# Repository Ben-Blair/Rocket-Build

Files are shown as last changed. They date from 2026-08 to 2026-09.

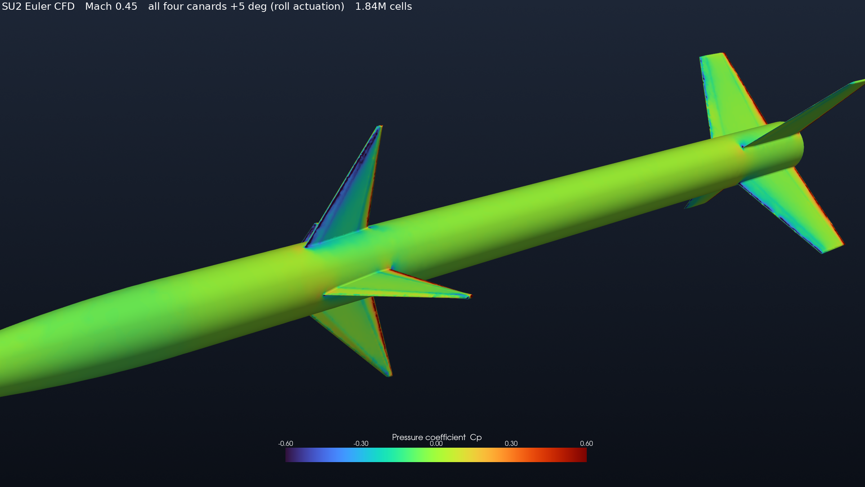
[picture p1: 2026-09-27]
out/cfd/renders/07_roll5_hero.png

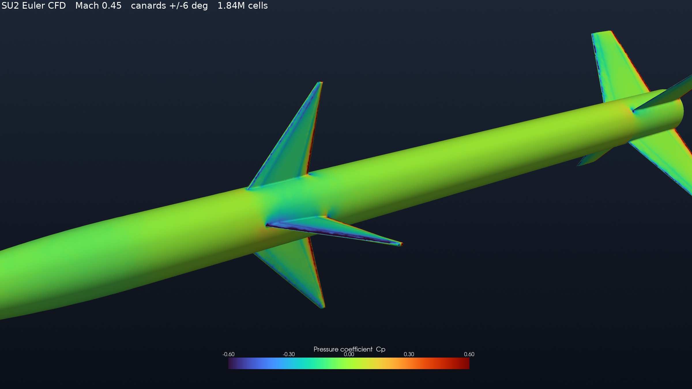
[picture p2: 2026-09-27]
out/cfd/renders/01_vehicle_cp.png

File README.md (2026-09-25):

# RocketSenior — canard-guided high power rocket

Senior capstone project: demonstrate closed-loop lateral guidance of a high power rocket
using forward canards, and handle the canard-wake-on-aft-fin interference problem
correctly.

This repository currently holds the **preliminary sizing tool**. It exists to answer the
questions you have to answer *before* you can draw anything in OpenRocket: how big is the
tube, how big are the fins, which motor, and can the canards actually do anything.

## Why a sizing tool instead of just using OpenRocket

OpenRocket is a verification tool. It answers "is *this specific* rocket stable, and how
high does it go." It cannot answer "what should my rocket be," because that depends on
constraints it knows nothing about:

- the internal diameter needed to house four canard servos (this sets your airframe size),
- the lateral acceleration you need for a visible manoeuvre,
- the static margin you are willing to trade away to get control authority,
- whether the canard wake reverses the sign of your roll moment.

This tool computes those, converges on a baseline, and then prints the numbers to type
into OpenRocket for an independent cross-check. Use both. Disagreement between them is
information.

## Quick start

```bash
pip install -r requirements.txt

python scripts/packaging_report.py   # what diameter do the actuators force on you?
python scripts/fetch_motors.py --diameter 54 --classes J K   # real thrust curves
python scripts/motor_trade.py        # rank every real L2 motor against the airframe
python scripts/sweep.py              # which (tube, motor, fin) combos meet requirements?
python scripts/baseline.py --plot    # full analysis + OpenRocket entry values
```

## Layout

```
out/
  RocketSenior.ork   GENERATED by scripts/make_ork.py -- do not hand-edit, see below
```

### The .ork is a build artifact, not the design

`out/RocketSenior.ork` is written from the same `DesignParams` the Python tool uses, and
`scripts/openrocket_check.py` regenerates it on every run. That is the point: the two
models cannot drift apart.

It also means **anything you change in the OpenRocket GUI and save back to that path is
destroyed the next time you run the check.** Open it to look, simulate, and cross-check
freely. If you want to tinker, `Save As` somewhere outside `out/` first. If a change is
worth keeping, it belongs in `design/configure.py` or `scripts/make_ork.py`, so that the
next regeneration carries it forward.

```
design/
  atmosphere.py   US Standard Atmosphere 1976, troposphere
  aero.py         Barrowman CNa & CP buildup, component drag buildup
  avionics.py     nav bay / nose packing, and the D7 flight computer trade
  bay.py          the printed canard bay: servo pockets, bearing seats, retainers
  configure.py    parameter set -> full vehicle -> requirement scoring, and the
                  frozen baseline airframe every script imports
  control.py      canard pitch authority, roll authority, wake interference, crossrange
  estimation.py   D8: observability per flight phase, attitude error budget, sensor specs
  flight_computer.py  the Stage 2 board: BOM, power budget, log budget, board envelope
  flutter.py      fin flutter margin
  geometry.py     nose / tube / fin set definitions, Barrowman CP geometry
  hinge.py        the hinge as a load path: shaft, bearing, coupling, root joint
  joints.py       all four tube joints -- a coupler costs bore, not length
  mass.py         geometric structural mass + editable subsystem budget, CG
  materials.py    material allowables, in one place
  motors.py       RASP .eng thrust curve parser + placeholder generic motors
  onshape.py      minimal Onshape REST API client
  onshape_build.py  emits Onshape Part Studio feature JSON
  packaging.py    actuator bay packaging + hinge moment + servo torque margin
  recovery.py     dual-deploy sizing, descent time, wind drift, soft-goods packing
  seal.py         the aft gas seal and the internal bulkhead, sized as pistons
  horizontal.py   horizontal-launch 3-DOF: fly the manoeuvre, then score the turn
  trajectory.py   3-DOF RK4 ascent to apogee
  tube_section.py airframe survival where holes are cut through it
  venting.py      static ports and bay vents: which volumes the altimeter may sense
scripts/
  agility_sweep.py      how agile can this airframe legally be, and what stops it
  avionics_report.py    nav bay + nose packing report and verdict
  avionics_trade.py     D7: the three flight computer architectures
  baseline.py           detailed baseline report + OpenRocket values
  bay_report.py         printed canard bay geometry and margins
  burn_time_study.py    why burn time is not a control-time knob
  canard_sweep.py       drives the CAD canards through +/-8 deg, checks clearances
  estimation_trade.py   D8: the four sensor sets, and what the estimate can know
  fetch_motors.py       download real .eng thrust curves from ThrustCurve.org
  hinge_report.py       hinge stack loads, fits and buildability
  horizontal_agility_sweep.py  the same search flown FLAT, where the answer changes
  make_*.py             build geometry in Onshape from the design modules
  motor_trade.py        rank every available L2 motor against the baseline airframe
  openrocket_check.py   automated cross-check against OpenRocket's engine
  packaging_report.py   diameter vs servo class table
  place_*.py            place built parts into Onshape Assembly 1
  recovery_study.py     descent, drift and the recovery footprint constraint
  robustness.py         Monte Carlo on static margin; sets the aft fin size
  flight_computer_report.py  the Stage 2 board's BOM, power, logging and envelope
  seal_report.py        the aft gas seal argument and check
  sil_demo.py           software-in-the-loop: closed-loop roll hold, bank-to-turn,
                        R12 failsafe -- synthetic sensors, no hardware
  sweep.py              design space sweep against requirements
  verify_cad.py         cross-check the design numbers against the Onshape model
  virtual_flight.py     3-D virtual flight: ballistic, skid-to-turn, bank-to-turn
docs/
  00-requirements.md    requirements, constraints, scoping, regulatory actions
  01-next-steps.md      ordered plan, the state of play, and 36 corrections
  02-motor-selection.md L2 motor trade study and decision
  03-openrocket-correlation.md  automated cross-check against OpenRocket's engine
  04-bill-of-materials.md       frozen parts list, masses and costs
  05-canard-module-build.md     CAD build sheet for the canard module
  06-avionics-selection.md      D7: the flight computer, and why it is staged
  07-state-estimation.md        D8: what the flight computer can know, and when
  11-agility-comparison.md      what this vehicle lacks versus a canard missile (VERTICAL)
  12-horizontal-agility.md      the same question flown flat -- 8.97 deg/s, and the
                                hinge bearing is what stops it. PROPOSAL, not frozen
  13-sil-demo.md                software-in-the-loop closed loop: how to run it, what
                                it proves, what it does not
  14-flight-computer-bom.md     the Stage 2 board, part by part: what to order, the
                                power and log budgets, and what was rejected
```

## How this fits with OpenRocket and RocketPy

Three tools, each for what it is actually good at. Do not try to make one do everything.

| Tool | Use it for | Do not use it for |
|---|---|---|
| **This repo** | Actuator packaging, control derivatives (`Cm_delta`, `Cl_delta`, `Cl_p`), canard/aft-fin wake interference, hinge moments, requirement-driven sizing sweeps across 100+ motors | Final apogee or drag numbers |
| **OpenRocket** | Validated stability and trajectory, Mach-dependent drag, dual-deploy and recovery sizing, fin flutter, the airframe truth a reviewer will trust | Anything involving a deflected control surface. It has no concept of one |
| **RocketPy** | 6-DOF flight with wind, Monte Carlo dispersion, and closed-loop control. `LinearGenericSurface` takes coefficient derivatives as functions of Mach, alpha, beta and body rates; `Controller` runs your control law at a fixed sampling rate against simulated IMU and barometer sensors | Preliminary sizing; it needs a vehicle before it can fly one |

The intended pipeline: size here → validate the passive airframe in OpenRocket → export
the derivatives from here into a RocketPy `LinearGenericSurface` → close the loop in 6-DOF
→ fly, and replace the interference factors with measured values.

## Model validity and what you must not trust

Read this before you quote any number from this tool in a report.

| Component | Status | Notes |
|---|---|---|
| Atmosphere | Solid | Standard model, valid to 11 km. |
| Barrowman CNa / CP | Good | Standard method. Valid subsonic, small alpha, attached flow. |
| Body lift (Galejs) | Approximate | Nonlinear term linearised about 4 deg alpha. |
| Drag buildup | ±20% at best | Component buildup with empirical form factors. Cross-check against OpenRocket, then against measured flight data. |
| Mass budget | Estimate | Every subsystem line is a guess until you weigh the part. Weigh things. |
| Trajectory | Good given the above | 3-DOF, no wind, perfect weathercocking. |
| Inertias | ±30% bulk, canard module measured | Crude analytical estimate for the airframe, with the canard module's CAD tensor superposed (`control.MEASURED_COMPONENTS`). Measure the rest before tuning gains. |
| Canard control derivatives | Approximate | Linear, quasi-steady, no wake effect on the canards themselves. |
| **Canard/aft-fin interference** | **Weakest part** | Empirical factors with no validation. Trends are believable, absolute values are not. Must be measured in flight. |
| Motor data | Real | 102 available 54 mm J/K certification curves from ThrustCurve.org in `data/motors/`. The `GENERIC` motors in `motors.py` are invented placeholders, kept only so the tool runs before a download. |

The interference model is the one to be honest about in your defense: it is a
physically-motivated parameterisation, not a validated prediction. The project plan
therefore makes measuring it a flight test objective rather than an assumption.

## Baseline result

75 mm (3 in) fiberglass airframe, 79.4 mm OD, 1361 mm long, 4 canards interdigitated 45°
from 4 aft fins, on a Cesaroni Pro54 J449 Blue Streak, actuated by four KST X08 Plus V6.0
servos on direct drive, with 100 g of nose ballast. 6.10 kg wet / 5.48 kg dry, apogee
1379 m (4525 ft), max Mach 0.531, static margin 2.03 cal at rail exit rising to 2.52 in
coast, 1.96 g of lateral authority at 8° of canard deflection, giving 424 m of crossrange
over an 11.4 second usable control window. Recovery is an 18 in drogue and 56 in main
deployed at 200 m, landing at 5.0 m/s after a ~0.93 km walk in a 15 mph wind.

Both fin sets were sized *together* by a Monte Carlo on margin robustness rather than
independently by nominal stability — canard semispan 0.85 cal, aft semispan 1.55 cal. They
pull in opposite directions, and searching them jointly under a probabilistic margin
constraint beats trading one against the other. See `docs/00-requirements.md` §7.

**The nose ballast is part of the design, not a contingency.** Real 9 g servos in place of
the 55 g budget placeholder removed ~180 g from ahead of the CG, which took P(SM < 1.0) to
1.8% against R1's 1% limit. 75 g of ballast is the minimum that satisfies R1; 100 g is the
design point and brings it to 0.6%. It is deliberately the last free parameter — a washer
stack you set after weighing the built vehicle, rather than fin area you commit to when you
cut the tube. See §7.1.

Every number above is an output of `scripts/baseline.py`. Regenerate them rather than
editing them by hand; they will move as the mass budget is replaced with weighed parts.

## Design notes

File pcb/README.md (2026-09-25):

# `pcb/` — the Stage 2 flight computer board

One project so far: **`flight_computer/`**, the custom STM32F405 board that
`docs/06` selected, `docs/07` gave sensors to, and `docs/14` turned into a BOM. This
directory is where that BOM becomes a schematic and a board. **As of 2026-09-24 it is
placed, routed, DRC-clean and has a JLCPCB fab + assembly package** in
`flight_computer/fab/` — read `fab/ORDERING.md` and "What is not done" at the bottom before
you order: two parts are out of stock and every assembly rotation needs a look in JLC's
preview.

## Opening it

```
open pcb/flight_computer/flight_computer.kicad_pro
```

The schematics are still **KiCad 8 file format** (`.kicad_sch` 20231120) and open
unchanged in KiCad 8, 9 and 10. **`flight_computer.kicad_pcb` no longer is** — the
layout pass (below) is done with KiCad's own `pcbnew` Python module, which saves in
whatever format the KiCad it's running under uses, and on this machine that's
**KiCad 10.0.6, board format 20260206**. Opening the `.kicad_pcb` in KiCad 8 or 9 will
prompt to upgrade the file. If that matters, say so before more layout work happens
on it — reverting is easy now and gets harder every pass after.

The symbol and footprint bodies embedded in the files were copied from this
machine's libraries — so if a symbol looks odd in another KiCad install, that is the
first place to look.

`sym-lib-table` registers one project-local symbol library,
`RocketSenior.kicad_sym`, for the three parts that needed one (below).
`fp-lib-table` registers one project-local **footprint** library,
`RocketSenior.pretty`, holding exactly one footprint —
`MMC5983MA_LGA-16_3x3mm_P0.5mm`, redrawn for `U5`, for the reason in "MMC5983MA"
below. Both tables use `${KIPRJMOD}`, so there is nothing to install; everything
else is stock KiCad libraries.

### Verified state

Reproducible from a clean checkout by regenerating in order (see "How the board gets
built" below — running only some of these steps, or out of order, does not match this
table):

| check | result |
|---|---|
| `kicad-cli sch erc` | **0 errors, 0 warnings** |
| `kicad-cli pcb drc --severity-all` | **0 errors, 0 unconnected**; 14 warnings, all library-footprint cosmetics — listed under "Routing" |
| netlist vs. `scaffold/design.py` | **57 real nets, exact match** (96 in the raw KiCad netlist — the other 39 are its own one-per-pin `unconnected-(REF-Pad)` placeholders for every NC pin, not a discrepancy) |
| footprint assigned on every component | **76 / 76** |
| `python scripts/pcb_placement_report.py` | **1 failure** (`C3`, accepted), median 2.60 mm |

```
bash pcb/flight_computer/scaffold/regen.sh      # close KiCad first; it refuses otherwise
```

which is, in order: ERC, netlist export, `gen_pcb.py`, `layout.py`, `finish.py` (hand-drawn
critical copper + Freerouting + silkscreen), full-severity DRC, the placement report, and
`fab.py`. Freerouting is **not deterministic** — to rebuild *this* board rather than an
equally valid re-route, pass `--ses routing/board.ses` to `finish.py` (see its docstring).
It needs `tools/freerouting-2.4.1.jar` (64 MB, gitignored): download it from
<https://github.com/freerouting/freerouting/releases>. Java is already installed.

`kicad-cli` is not on `PATH` by default on this machine; it lives at
`/Applications/KiCad/KiCad.app/Contents/MacOS/kicad-cli`.

**Do not run `layout.py` twice in a row on the same file, and do not run it without
regenerating the skeleton first.** It loads whatever `flight_computer.kicad_pcb`
already contains and adds a full new set of passives/vias/zones on top; run on its
own prior output it silently doubles everything and every number above stops
matching. `gen_pcb.py` always rebuilds the board from scratch, so the correct order
is always: export the netlist, run `gen_pcb.py`, then run `layout.py` exactly once.

Before 2026-09-24 the 133 unconnected items were every signal net — the board was placed
and planed but not routed. They are all routed now; see "Routing".

Nothing here moved by exclusion — every DRC violation was fixed in geometry:

| | first pass | then | now | why |
|---|---|---|---|---|
| DRC violations | 23 | 11 | **0** | 12 were `U5`'s adjacent-pad clearance (fixed in copper, see "MMC5983MA"); the last 11 were GND stitching vias landing on `U2`'s pads — see "Planes" below |
| unconnected items | 136 | 133 | **133** | the 3 unstitched `GND` pads are stitched; the rest is unrouted signal |
| placement failures | — | 14 | **2** | the pre-routing placement pass — see "Placement" below |

## Placement — the pass before routing, and the check that holds it

**ERC and DRC are connectivity checks and cannot see geometry.** Both passed on a board
whose 12 pF crystal load cap sat **21.5 mm** from its crystal, with the 8 MHz oscillator
node routed the length of the MCU and past the IMU. `design/pcb_placement.py` is the check
that closes that gap, `scripts/pcb_placement_report.py` prints it, and `scripts/baseline.py`
carries the verdict so it cannot regress quietly. Read that module's docstring before
changing a limit — in particular, why the check is scoped to two-terminal passives plus
three named nets rather than run over every pad.

What moved, and the measured effect:

| | before | now |
|---|---|---|
| `OSC_IN` (crystal to MCU, worst pad) | 14.39 mm | **3.75 mm** |
| `OSC_OUT` | 5.98 mm | **4.96 mm** |
| `GNSS_RF` (`U8` pin 11 to the u.FL) | 13.93 mm | **2.59 mm** |
| `C2`, 100 µF bulk, to the star point | 11.21 mm | **4.60 mm** |
| `R1`/`C4`, the regulator's enable and bypass | 14.3 / 13.6 mm | **2.99 / 1.98 mm** |
| median over all checked pads | 3.47 mm | **2.59 mm** |
| failures | 14 | **2** |

The moves that made room, all in `scaffold/gen_pcb.py`'s `PLACE`:

- **`J10` and `SW1` were in the two best pockets on the board** and are bring-up-only
  parts. `J10` (debug UART) held a 3.5 × 11.2 mm channel beside `U1` — which is *why*
  `C2`/`C4`/`R1` had been hand-relocated 14 mm away in an earlier pass, with a note saying
  the corner was saturated. It was saturated by a debug header. `SW1` sat in the only pocket
  that could take the crystal. Both are grouped with `J3` on the aft edge now; `NRST` is on
  the SWD header anyway, so `SW1` belongs there electrically as well as ergonomically.
- **`TP3` (a GND probe point) had claimed the gap between `U1` and its VIN cluster.** A test
  point's courtyard is 1.25 × 0.00 mm, so it slips into gaps no real part can claim.
- **`J5` moved to the forward edge** beside `U8`'s RF pad, which points at the nose where
  the antenna is. `U8` shifted 2.0 mm aft to open the strip — its courtyard is 11.8 mm wide
  against a 9.7 × 10.1 mm package and left only 3.0 mm of edge for a 4.4 mm connector.
- **`Y1` moved against `U2` pins 5/6, at 180°** so its `OSC_IN` pad faces the MCU and the two
  traces do not cross.

**`U5` did not move, and is confirmed not to have moved**: pad 1 is still at
(162.7500, 109.2250) — `pcb_placement.self_check()` asserts it on every run, because a
pad-rotation sign error would otherwise be invisible in the aggregate.

### The two remaining failures, both accepted

`C3.1` at **3.40 mm** and `R1.1` at **2.99 mm** against a 2.5 mm `VIN` limit. The aft-left
corner really is saturated once the four servo headers, the pack connector, the regulator,
the inductor and the power LED are in it — that part of the earlier note was right. Both are
about 1 mm over a limit set by judgement rather than by a datasheet. If the buck's input loop
ever needs to be tighter than this, the lever is `docs/14`'s own rule — *"if layout wants
more, take it out of height, not width"* — not another shuffle of the same corner.

## How the schematic is drawn, and why it looks like that

Four hierarchical sheets — `power`, `mcu`, `sensors`, `io` — under a root sheet that
carries the board-level notes.

**There are no drawn buses.** Every pin gets a short stub with a global label or a
power symbol on the end. That is a deliberate trade: it makes the netlist exactly
what `design.py` says and nothing else, and it means the auto-placement of symbols on
the sheet carries no meaning at all. **Rearranging the sheets into something a human
would draw is expected work, and it cannot break connectivity** as long as you move
labels with their pins. Sheet sizes were picked as the smallest ISO size each fit on
(io A3, power/sensors A2, mcu A1).

## Bus map — this is `docs/14`, unchanged

```
SPI1  CS1_IMU     PA4    ICM-42688-P    alone on the bus, 1 kHz burst on DMA
SPI2  CS2_MAG     PB12   MMC5983MA      100 Hz
      CS3_BARO    PC7    MS5611         50 Hz
SPI3  CS4_FLASH   PB5    W25Q128JV      log flash, write-mostly
USART1 PA9/PA10          MAX-M10S       10 Hz UBX
USART2 PA2/PA3           debug console  bring-up only
TIM4  CH1-4  PB6 PB7 PB8 PB9            4x servo PWM, 333 Hz / 1520 us
SWD   PA13 PA14 (+ PB3 SWO)
USB   PA11/PA12 full speed, 8 MHz HSE crystal
```

CS net names are `CS1_IMU`, `CS2_MAG`, `CS3_BARO`, `CS4_FLASH` so both `docs/14`'s
number and the function are in the name.

**Flash only — no microSD**, per `docs/14`'s socket-eject argument. The SDIO pins
(PC8-PC12/PD2) are not all free because SPI3 took PC10-PC12; if a microSD is ever
wanted, that is the trade to reopen.

**No pyro, no continuity, no e-match anything.** An independent StratoLoggerCF fires
the charges. This is `docs/14`'s non-negotiable and the board honours it.

## Things found while drawing it

These came out of reading datasheets to place pins, and several of them change a part,
a component count or a footprint. **None of them touches ±4000 or the airframe
freeze.**

### 1. `docs/14` names the wrong regulator — TPS62163 is 5.0 V, not 3.3 V

`docs/14`'s BOM row reads `3.3 V regulator | TPS62163DSGT`. TI's own device-options
table (SLVSAM2E, *TPS62160/61/62/63*, §5 Device Voltage Options) maps the suffixes:

| output | part |
|---|---|
| adjustable | TPS62160 |
| 1.8 V | TPS62161 |
| **3.3 V** | **TPS62162** |
| 5.0 V | TPS62163 |

**The 3.3 V part is TPS62162DSGT.** Verified against TI's own PDF, not a mirror:
`ti.com/lit/ds/symlink/tps62162.pdf`, SLVSAM2E §5 *Device Voltage Options*, which also
confirms DSG = WSON(8) and the DSG pinout the power sheet is wired to (1 PGND, 2 VIN,
3 EN, 4 FB, 5 AGND, 6 VOS, 7 SW, 8 PG).

**This is now fixed in all three places** — the schematic already had it, and
`docs/14-flight-computer-bom.md` and `design/flight_computer.py` have been changed from
`TPS62163DSGT` to `TPS62162DSGT`. `out/flight_computer.txt` was regenerated
(`python scripts/flight_computer_report.py --write`) so the report no longer copies the
wrong line. The intent in `docs/14` was never ambiguous ("3.3 V regulator", 2S in,
112 mA logic rail) — it was a wrong MPN, and ordering the line as written would have put
5.0 V onto the 3.3 V logic rail.

Wired per the same datasheet: `FB` (pin 5) to AGND, which is what TI specifies for
the fixed-output versions; `VOS` (pin 6) is the output sense and goes to the 3.3 V
rail; `PG` is open-drain and gets a 100 k pull-up, landed on PC13 so firmware can see
the rail come up.

### 2. The magnetometer needs a 10 µF capacitor that was in nobody's parts count

MMC5983MA **pin 10 is `CAP`** — "Connect a 10 µF capacitor for SET/RESET" (MEMSIC
MMC5983MA Rev A, Pin Description). That is not decoupling; it is the reservoir that
drives the degauss coil, and the SET/RESET cycle is exactly what this vehicle needs
the magnetometer for (`docs/12`, roll observability). It is `C23` on the sensors sheet.

Full pin list taken from that table, since no stock KiCad symbol exists:
`1 SCL/SPI_SCK, 2 VDD, 3 NC, 4 SPI_CS, 5 SPI_SDO, 6-8 NC, 9 GND, 10 CAP, 11 GND,
12 NC, 13 VDDIO, 14 NC, 15 INT, 16 SDA/SPI_SDI`.

### 3. The MS5611 has *two* CSB pins, and the stock KiCad symbol is right

`Sensor_Pressure:MS5611-01BA` puts `CSB` on both pin 4 and pin 5, which looks like a
library bug. It is not. The TE datasheet's PIN CONFIGURATION table has a merged cell
spanning pins 4 and 5 — "Chip select (active low), **internal connection**". Both
pads go to `CS3_BARO`. Left as-is, this is the kind of thing that gets "fixed" during
layout and quietly breaks the part.

## Pinouts, and how much to trust each one

| part | pinout source | confidence |
|---|---|---|
| STM32F405RGT6 | stock `MCU_ST_STM32F4` symbol | high |
| MS5611-01BA03 | **TE datasheet read directly** (pin table above) | high |
| MMC5983MA | **MEMSIC Rev A read directly** — pinout *and* land pattern, and the footprint is now redrawn from it | high |
| W25Q128JVS, MAX-M10S, USBLC6 | stock KiCad symbols | high |
| TPS62162DSGT | **TI SLVSAM2E read directly** | high |
| **ICM-42688-P** | **TDK DS-000347 rev 1.6 read directly** | high |

## Datasheet verification — the pinouts are no longer single-sourced

An earlier revision of this file said DS-000347 could not be fetched and that the
ICM-42688-P pinout rested on one SnapEDA-derived symbol. **That has been closed.** The
403 was not a paywall or a bot wall on the file — it was a missing browser
`User-Agent`/`Referer`. This gets the real PDF:

```
curl -L -o ds347.pdf \
  -H "User-Agent: Mozilla/5.0 (Macintosh; Intel Mac OS X 10_15_7) \
AppleWebKit/537.36 (KHTML, like Gecko) Chrome/140.0.0.0 Safari/537.36" \
  -H "Referer: https://product.tdk.com/" \
  https://product.tdk.com/system/files/dam/doc/product/sensor/mortion-inertial/\
imu/data_sheet/ds-000347-icm-42688-p-v1.6.pdf
```

The same trick (UA + a `Referer` on the vendor's own domain) worked for MEMSIC and TI.
Do not re-record any of these as "unfetchable".

| document | what was read | SHA-256 of the PDF |
|---|---|---|
| TDK InvenSense **DS-000347 rev 1.6**, 110 pp | §4.1 Table 10 *Signal Descriptions*, Fig. 5 pin-out, §10.2 package drawing | `5710af93…2ce1b9c` |
| MEMSIC **MMC5983MA Rev A**, 20 pp (4/3/2019) | Pin Description table, p.11 SPI connection, p.20 package drawing + LAND PATTERN | `d82083b9…5731f7` |
| TI **SLVSAM2E** (TPS62160/61/62/63) | §5 Device Voltage Options, §6 DSG pin configuration | — |
| u-blox **UBX-20035208 R08**, 24 pp (30-Jan-2026) | §3.1 Table 10 *Pin assignment*, §4.2 Table 13 *Operating conditions* | `e36d9c85…8df6bec` |

**`U8`'s whole pin map was checked against Table 10 and is correct as drawn — including
every no-connect.** Pin 15 `VIO_SEL` is the one worth naming: *"Connect to GND for 1.8 V
supply, or leave open for 3.3 V supply."* **Open is the 3.3 V setting and is deliberate**;
tying it to GND would drop `V_IO` to 1.8 V and break every interface on the board. Pins 13
and 14 (`LNA_EN`, `VCC_RF`) are outputs, open because the antenna is passive (`docs/14`).
Pin 6 is `V_BCKP` and sits on `+3V3`, i.e. the same rail as `VCC`, so the backup domain dies
with the board and **every power-up is a cold start** — accepted, not missed: `docs/14`
budgets 60 minutes armed on the pad, which is many times a cold TTFF.

### ICM-42688-P pin table, from DS-000347 §4.1 Table 10 verbatim

| pin | name | datasheet says | schematic does |
|---|---|---|---|
| 1 | AP_SDO / AP_AD0 | SPI serial data out (4-wire) | `SPI1_MISO` |
| 2 | RESV | *No Connect or Connect to GND* | NC |
| 3 | RESV | *No Connect or Connect to GND* | NC |
| 4 | INT1 / INT | interrupt 1 | `IMU_INT1` |
| 5 | VDDIO | IO supply | `+3V3` |
| 6 | **GND** | power supply ground | `GND` |
| 7 | **RESV** | **"Connect to GND"** — not optional | **`GND`** |
| 8 | **VDD** | power supply voltage | `+3V3` |
| 9 | INT2 / FSYNC / CLKIN | see the FSYNC note below | NC |
| 10 | RESV | *No Connect or Connect to GND* | NC |
| 11 | RESV | *No Connect or Connect to GND* | NC |
| 12 | AP_CS | SPI chip select | `CS1_IMU` |
| 13 | AP_SCL / AP_SCLK | SPI serial clock | `SPI1_SCK` |
| 14 | AP_SDA / AP_SDIO / AP_SDI | SPI serial data in (4-wire) | `SPI1_MOSI` |

**Pins 6 and 8 were the ones worth checking, and the SnapEDA symbol had them right:
6 is GND, 8 is VDD.** The whole symbol matched, pin for pin. The old warning about
VDD/GND swapped on a 2.5 × 3.0 mm LGA can be retired.

**What did change: pin 7.** The datasheet distinguishes the reserved pins, and it is
the only one of the five that reads *"Connect to GND"* flat, with no "No Connect or"
in front of it. It was a no-connect here — the conservative-looking choice that was
in fact the wrong one. It is now on `GND` in `scaffold/design.py`, the schematic and
the board. Pins 2, 3, 10 and 11 genuinely are "No Connect **or** Connect to GND", so
leaving them NC is compliant and they stay NC.

**FSYNC (pin 9) is safe as a no-connect, but only because of a register default.**
`INTF_CONFIG5` (bank 1, 0x7B) bit 2:1 `PIN9_FUNCTION` resets to `00` = INT2, which is
an *output*, so a floating pin 9 drives nothing and floats nothing. The datasheet's
"Connect to GND if FSYNC not used" applies to the FSYNC configuration only. **This is
now a firmware constraint: do not set `PIN9_FUNCTION` to `01` (FSYNC) on this board.**
There is no pad to ground it from if you do. Note `FSYNC_CONFIG` (0x62) resets to
`0x10`, i.e. FSYNC tagging into `TEMP_OUT` LSB is *already enabled* — harmless while
pin 9 is INT2, not harmless if you switch the pin.

### Footprints, against the two land patterns

**ICM-42688-P — `Package_LGA:LGA-14_3x2.5mm_P0.5mm_LayoutBorder3x4y` is correct, no
change.** DS-000347 §10.2 gives the package, and the KiCad footprint reproduces it
exactly: pad centres at **±1.1625 mm** on the 4-pin columns and **±0.9125 mm** on the
3-pin rows — the same two numbers the drawing dimensions as `2X 1.1625` and
`2X 0.9125`. Body 3.0 (E) × 2.5 (D) mm, 0.5 pitch, 4+3+4+3 with pin 1 top-left in top
view and counter-clockwise numbering. Pads are 0.625 × 0.35 mm against a 0.475 × 0.25
terminal (`L` × `W`), i.e. a normal IPC expansion. The library entry is labelled for
an ST LSM6DS3TR-C, which is why it needed checking; the geometry is the same package
and it lands.

**MMC5983MA — the assigned footprint was wrong, and it has been changed.** It was
`Package_LGA:LGA-16_3x3mm_P0.5mm_LayoutBorder3x5y`, which is **5 pads on two sides and
3 on the other two**. The MMC5983MA is **4 pads on every side** (MEMSIC Rev A p.20,
top view: 4/3/2/1 across the top, 5-8 down the left, 9-12 across the bottom, 16/15/14/13
down the right). Nothing but the pitch would have matched. That part would not have
soldered.

It is now **`RocketSenior:MMC5983MA_LGA-16_3x3mm_P0.5mm`**, a project-local
footprint in `RocketSenior.pretty` drawn for this part, and it matches the MEMSIC
LAND PATTERN drawing exactly:

| | MEMSIC Rev A p.20 | `RocketSenior:MMC5983MA_LGA-16_3x3mm_P0.5mm` |
|---|---|---|
| pads per side | 4 | 4 |
| pitch | 0.500 | 0.5 |
| pad size | 0.450 × 0.300 | 0.45 × 0.30 (rot 90 on the side columns) |
| row-to-row, centre to centre | 2.550 both axes | ±1.275 both axes |
| pad 1 | right end of the top row | right end of the top row |

(The 2.550 dimensions are centre-to-centre, not outer-edge — the extension lines land
on the pad midlines. Checked by magnifying the drawing; it is the one reading that
makes the numbers close.)

#### Why it is project-local, and why `U5` is at 0° and not 270°

The copper above is the same copper the stock `Package_LGA:LGA-16_3x3mm_P0.5mm`
has — that library entry is fine, and it is where this geometry was copied from.
The difference is **numbering**. Both number counter-clockwise, 4 per side, so pin
*n* lands on pad *n* for all 16; what differs is where the sequence starts. The
stock footprint's pad 1 is the top of the **left column**, while the chip's pin 1 is
the right end of the **top row** — one 90° step apart (stock pad *n* sits where chip
pin *n+4* would). Left at 0° on the stock footprint, the die sits rotated 90° CCW off
datasheet-upright and mag X/Y come out swapped against the board.

**For one revision that was corrected by placing `U5` at 270°. The axis answer was
right and the copper was wrong.** KiCad stores each pad's rotation **absolutely** in
the board file, not relative to its footprint: rotating the footprint 270° subtracts
270° from every pad's effective local angle. The side pads lose the 90° that made a
0.45 × 0.30 rectangle fit a 0.5 mm pitch, the 0.45 mm dimension ends up running
*along* the pitch, and adjacent-pad gaps collapse from 0.200 mm to **0.05 mm** —
under the `Default`/`Power` netclass's 0.127 mm and under JLCPCB's 0.127 mm minimum.
That produced 12 DRC clearance violations. They were never excluded; the geometry
was fixed.

The fix moves the 90° step out of the *placement* and into the *footprint*: the
local copy carries the same land pattern with the **chip's own numbering**, so `U5`
is placed at **0°**, upright, and nothing is rotated. Consequences:

- **Copper is the land pattern again.** All 16 adjacent pairs measure **0.200 mm**
  edge-to-edge (0.5 pitch − 0.30 pad) on the four sides, and 0.212 mm across each
  corner. Measured from `pcbnew`'s real pad polygons, not from size arithmetic — a
  pad with a wrong rotation flag cannot hide from that check. The 12 clearance
  violations are gone from `kicad-cli pcb drc`.
- **The die is datasheet-upright, and the axis convention `docs/12` needs is
  unchanged.** Mag axes aligned with board, mounting matrix board-in-airframe only.
  The strongest evidence that nothing moved: **every one of the 16 pad centres, and
  every net on them, is bit-identical to the old 270° placement.** Pad 1 is still at
  (162.7500, 109.2250). Only the pad rectangles' orientation changed. `docs/12` leans
  on this part for roll observability, so this was worth confirming rather than
  assuming.
- **`PLACE["U5"]` in `scaffold/gen_pcb.py` is `0` now**, `scaffold/design.py` and
  `scaffold/gen.py` both name the local footprint, and `gen.py` writes the
  `fp-lib-table` that resolves it — so a regen cannot revert any of it. `ksym.py`
  searches `RocketSenior.pretty` before the stock library, so a project-local redraw
  always wins over a same-named stock part.
- **Pin 1 is marked three ways, all at the top-right corner**: the silkscreen arrow
  above pad 1, the `F.Fab` outline chamfer, and a deliberately oversized filled
  circle on `F.Fab` at (1.9, −1.9). That circle used to be welded on at generation
  time by `gen_pcb.py`'s `EXTRA_FAB_MARK`, because the part was rotated on a
  footprint labelled for its sibling; it is now **drawn into the footprint itself**,
  so it is right in the footprint editor and on any other board too. Do not re-add a
  `U5` entry to `EXTRA_FAB_MARK` — that would draw the dot twice.

KiCad's own `--schematic-parity` check resolves the local library and reports **no
issue at all for `U5`** — the board's embedded copy of the footprint matches the
library exactly.

### Residual risk

- **Solder-paste apertures are the library's, not the vendor's.** Neither vendor
  publishes a stencil recommendation; both footprints use KiCad's default 1:1 paste
  layer. For two bottom-terminated 0.5 mm-pitch parts that is normal practice, not a
  verified number.
- **No 3D models were checked**, so nothing has confirmed that the ICM's pin-1 corner
  chamfer or the MMC's package outline agree with the footprint's fab layer. The
  local MMC footprint keeps the stock `LGA-16_3x3mm_P0.5mm.step` reference — the
  package body is the same, but **the model was drawn for the stock numbering**, so
  if it carries a pin-1 feature of its own it will point at the top of the left
  column, not the top-right corner where this footprint's pin 1 is. Believe the
  `F.Fab` marks, not the render.
- **The MMC5983MA's `MAG_CAP` net is not really a separate node.** MEMSIC Rev A p.11:
  "VDD and CAP pins are shorted together inside the device." `C23` (10 µF) therefore
  sits on the same node as `+3V3` through the package. That is exactly what MEMSIC's
  own SPI connection diagram draws, so it is kept as drawn — but **do not route
  `MAG_CAP` as a signal**, and do not let anyone "clean it up" by merging it into
  `+3V3` on the schematic, which would move the 10 µF away from the CAP pad.
- **DS-000347 rev 1.6 is not the newest revision** — TDK is at least at 1.9. Nothing
  read here (pin table, package drawing, `PIN9_FUNCTION`, `FSYNC_CONFIG`) is the kind
  of thing that moves between revisions, but the ordering check before fab should be
  done against whatever revision is current then.
- **The ICM footprint's toe extends to 1.475 mm against a 1.5 mm package half-width**,
  i.e. the land sits entirely under the body with no external fillet. That is inherent
  to LGA and matches the drawing; it just means optical inspection cannot see these
  joints and X-ray is the only real check.

## Power, and the rail split `docs/14` asked for

`docs/14`: the KST X08 runs straight off the 2S pack, so there is no BEC, and
"separate supply from the IMU" becomes a separate feed and filter off a star point at
the pack. On the board that is:

- **`VBATT`** — raw 2S from `J1`, **two wire pads for an 18 AWG XT30 pigtail** (was a
  JST-GH rated 1 A per contact — see "Routing and fab"). Goes to the four servo headers `J6`-`J9`
  and nowhere else. Its own netclass (`ServoPower`, 1.2 mm tracks, 0.3 mm clearance)
  because it carries the **4.1 A all-four-stalled** case from `docs/14`.
- **`VIN`** — the logic branch, through ferrite `FB1`. Making it a separate net is
  what puts the star point in the netlist instead of in a comment.
- **`+3V3`** — 1 A buck. The 112 mA logic rail has plenty of headroom.
- **`VDDA`** — through `FB2` off `+3V3`, with 1 µF ‖ 10 nF.

Each servo header is a normal 3-pin SIG/V+/GND so a servo lead plugs straight in.
**Nothing on this board feeds a servo from 3.3 V** — check that first if you rearrange
the power sheet.

`J4` is USB-C, and **VBUS is not connected to any rail**: the board is powered from
the pack. `D1` + solder jumper `JP1` (**default open**) exist so you can close the
link and run the board off USB on the bench without a pack. Do not close it with a
pack plugged in.

## Board

70.0 × 45.0 mm outline on `Edge.Cuts`, 4 layers, 1.6 mm, ENIG, four M2.5 corner
holes. Against `docs/08`'s sled that leaves +39.0 mm long / +14.4 mm wide / +9.1 mm
tall. **`docs/14`: hold 70 × 45; if layout wants more, take it out of height, not
width** — the board is the one line in the nav bay whose size is a design decision.

Major parts sit at `docs/14`'s zoning; passives are placed next to the pin they
decouple:

- **aft/left** — pack in, regulator, four servo headers. The noisy end.
- **centre** — MCU, with the IMU below it over the solid ground pour.
- **forward/right** — magnetometer `U5` and the GNSS receiver, diagonally as far from
  the servo headers and the battery lead as a 70 × 45 outline allows.

That last one is a requirement, not aesthetics:
`estimation.required_magnetic_cleanliness()` gives **18.0 mgauss** against
**40 mgauss** from a single untwisted 1 A servo lead at 50 mm. Twisted pairs on the
servo leads and keeping the 2S run off the forward end are how that budget gets met.

Netclasses are in the `.kicad_pro`, mirrored by `NETCLASS_PATTERNS`/`TRACK_WIDTH` in
`scaffold/layout.py`: `Default` and `Power` at 0.127 mm clearance (anything wider fails
against the LQFP-64 and LGA pad pitches), `ServoPower` at 0.3 mm / 1.2 mm tracks, `USB` with
a 0.2 mm / 0.4 mm differential pair, and **`RF` at 0.36 mm for `GNSS_RF`**.

**0.36 mm is 50 ohm on this stackup**, and 50 ohm is what the part asks for: MAX-M10S `RF_IN`
has `Zin` = 50 ohm with a built-in DC block (u-blox UBX-20035208 R08, Table 13). Hammerstad
microstrip over `In1` — h = 0.2104 mm, er = 4.5, t = 35 um — gives **59.9 ohm at the
`Default` 0.25 mm** and 50.0 ohm at 0.360 mm. `GNSS_RF` had been sitting in `Default`, i.e. a
~20% impedance error on the one net on this board that has an impedance.
`scripts/pcb_placement_report.py` prints the solve rather than leaving 0.36 as a constant.

### One routing rule that is not a netclass: the `VBATT` trunk

`ServoPower` is a single width, but `VBATT` carries two very different currents. The branches
to `J6`-`J9` take **<= 1 A each** and 1.2 mm is right for them (and is what fits a 2.54 mm
header). The trunk from `J1` to the branch point carries `docs/14`'s **4.1 A all-four-stalled**
case, which that document explicitly calls "a conductor question".

On 1 oz external copper, 1.2 mm is **2.73 A** at a 10 degC rise; at 4.1 A it runs about
**27 degC** hot. 2.0 mm brings that to ~11 degC. **Route the `J1` -> branch-point trunk at
2.0 mm**, keep the branches at 1.2 mm, and keep the whole run tight over `In1` (see "Planes").
It is a short run through an otherwise empty corner, so this costs nothing — but it has to be
done by hand, because a netclass cannot express "this part of this net".

## How the board gets built — two separate, one-way passes

`flight_computer.kicad_pcb` is not hand-edited directly and is not one script's
output; it comes from two passes that must run **in order**, and each one **destroys
what the other one did if run out of order or twice**:

1. **`scaffold/gen_pcb.py`** — rebuilds the *entire* board from KiCad's own exported
   netlist: layers, stackup, nets, every footprint at its `PLACE[...]` position (or
   parked off-board if not in `PLACE`), the outline and its notes. This is the
   skeleton generator described lower down; it has no memory of anything a previous
   layout pass did. Run it after any schematic/`design.py` change, before touching
   layout.
2. **`scaffold/layout.py`** — the hand-layout pass, run once against that skeleton
   with KiCad's own bundled Python (it needs the real `pcbnew` module, which is not
   on a normal `python3`):
   ```
   /Applications/KiCad/KiCad.app/Contents/Frameworks/Python.framework/Versions/3.9/bin/python3 \
     pcb/flight_computer/scaffold/layout.py pcb/flight_computer/flight_computer.kicad_pcb
   ```
   It places every passive next to the pin it decouples (anchored by shared net,
   nearest IC preferred over a connector, with a small hand-curated override table
   for rail/bulk caps that a shared `+3V3`/`VBATT`/`GND` net can't disambiguate on
   its own — see `OVERRIDE_ANCHOR` in the script), pours and fills the ground planes,
   stitches every surface-mount `GND` pad into them with its own via, adds the one
   hand-drawn stitch in `MANUAL_GND_STITCH` (`U1`'s exposed pad — see "Planes"), and
   stops. **It does not route signal nets** — see below.

Running `layout.py` a second time on its own output does not "improve" the layout —
it loads whatever is already in the file and adds a whole second set of
passives/vias/zones on top, silently doubling everything. If you need to change
something after `layout.py` has run, either edit the `.kicad_pcb` directly in KiCad,
or start over from step 1.

### Placement

All 53 passives that `gen_pcb.py` parks off-board are placed by `layout.py`, each
next to the specific pin it serves (not just "somewhere on the net" — see
`resolve_anchors` / `OVERRIDE_ANCHOR`). Collision is resolved against real `F.CrtYd`
courtyard geometry read from `pcbnew` (not a pad-bounding-box guess, which
undercounts a JST connector's or a switch's real body badly), by the same kind of
push-apart relaxation `gen_pcb.py` already used for the major parts. Four items
needed a hand nudge afterward into open space nearby, each individually checked
against `kicad-cli pcb drc` before being hard-coded — see `MANUAL_FIXUP` in the
script; the comments there say why each one didn't fit where the automatic pass put
it. The aft/left corner (four servo headers + `J1` + the regulator + `J10`, all
`docs/14` zoning decisions, not this pass's to move) is genuinely saturated — there
was no pocket left near `J1` itself for its own bulk caps, which live one zone over
instead.

### Planes

`In1.Cu` and `In2.Cu` are each one solid `GND` pour, the whole board.

**`In2` used to be split in two** at `x = 120.5`, with a 1.5 mm copper gap, so that "servo
return current has no direct path across `In2` under the sensors". **That never worked and
could not have**: both halves were net `GND` and `In1` is an unbroken full-board pour, so
every stitching via tied them together. They were one node the whole time.

What the gap did do was real. The stackup is `F.Cu` / 0.2104 prepreg / `In1` / 1.065 core /
`In2` / 0.2104 prepreg / `B.Cu`, so a `B.Cu` trace references `In2` at 0.21 mm while `In1`
is 1.28 mm away. **Any `B.Cu` trace crossing `x = 120.5` lost its return path** — and
`SERVO1-4`, `+3V3` and `VIN` all have to cross it, because the MCU is at `x = 137` and the
regulator and servo headers are at `x = 103.5-117`. The split was costing exactly the thing
it was meant to protect, on the layer where the routing has to happen.

**Servo-return isolation comes from routing, not from a slot**: keep the `VBATT` trunk tight
over `In1` so its return image stays directly underneath it. At 0.21 mm of prepreg that image
is a ~0.1 mgauss dipole at the magnetometer against the 18.0 mgauss budget — four orders of
margin, which is why the binding magnetic risk in that budget is the untwisted servo *leads*
off-board and never the on-board copper. A genuine split would have to slot `In1` as well and
enforce a single star point, and it would put a plane slot under a board carrying both an IMU
and a magnetometer. That is a decision, not a default.

Every `GND` pad gets its own short stub and via down into `In1`. The escape direction is
searched over eight directions at five increasing offsets, and the first position clearing
**0.40 mm** to the nearest other-net pad *bounding box* is taken; if none clears, the best
available is used and the script **says so** on stdout.

That replaced a best-of-four-cardinal-directions-at-one-offset search measured **centre to
centre**, which is what produced all 11 of the previous pass's DRC violations: centre-to-centre
treats a 1.7 mm LQFP-64 finger and an 0402 terminal as the same point, so an escape "1.4 mm
from the centre" of a long pad was landing 0.10 mm off its edge. On a 0.5 mm-pitch part the
cardinal directions all run down a row of pins and the diagonals are the only way out.

**The three `GND` pads that used to be left out are stitched. There are no `GND`
items in `kicad-cli pcb drc`'s unconnected list at all now.** What they actually
were is worth recording, because an earlier revision of this file diagnosed two of
them wrongly:

- **`SW1` pin 2 and `J5` pin 2 — the zone filler was innocent.** This file used to
  say the filler was pruning the copper around their vias as an "island". It was
  not: those vias sit inside solid `In1` pour, checked against the filled polygons
  with holes accounted for. The real cause is **duplicate pad numbers**. `SW1`
  (`SW_SPST_TL3342`, a 4-terminal tactile switch) has *two* pads numbered `2`, and
  `J5` (U.FL) has two as well — one netlist pin, two separate lumps of copper.
  `stitch_gnd_vias` walked the netlist and took `next(p for p in fp.Pads() if
  p.GetNumber() == pin)`, i.e. **the first pad only**, so the second lump of each
  pair never got a stub and never touched the plane. The loop now stitches *every*
  pad carrying the number. It also skips through-hole pads, which reach `In1`
  through their own barrels and need no escape via — that is what keeps `J4`'s four
  same-numbered USB-C shield tabs from collecting four redundant vias, and it is why
  the stitched-via count reads 65 rather than 69 while *more* copper is connected.
- **`U1`'s WSON-8 exposed pad (pin 9)** is real and is handled by hand. It sits
  exactly at the footprint's own centre on a 2×2 mm body with pins 6/7 straddling
  it, so no cardinal escape direction clears them, and a via dropped into the pad
  itself would be an unplugged 0.3 mm drill under a bottom-terminated part — a
  solder-wicking risk taken for nothing, since the TPS62162 dissipates on the order
  of **40 mW** here (112 mA at 3.3 V, ~90 % efficient) and needs no thermal path at
  all. `MANUAL_GND_STITCH` in `scaffold/layout.py` runs a 0.25 mm `F.Cu` track east
  out of the pad at *y* = 139.25 to pin 5 (`GND`), which already has its own stub and
  via. The only other-net copper it passes is pin 6 (`+3V3`), and the measured gap
  is **0.250 mm** against the 0.127 mm `Power` requirement. If a proper thermal via
  array under the EP is ever wanted, it is a fab-time decision about plugged vias,
  not a connectivity one.

### Routing and fab (2026-09-24) — `scaffold/finish.py` and `scaffold/fab.py`

`layout.py`'s greedy router (`route_signal_nets`) is still off, for the reason it always
was: two-bend Manhattan paths cannot route an LQFP-64 escape on a populated board, and it
fell back to shorts. The board is routed by a **third pass, `scaffold/finish.py`**, run
exactly once on `layout.py`'s output:

1. **Inner layers typed as power planes.** `In1`/`In2` were "signal" layers; left that way
   Freerouting routes through the GND pours and the zone filler cuts the plane round each
   track.
2. **Copper a netclass cannot express, drawn by hand and locked** (Freerouting routes
   around locked copper):
   - **`VBATT` at 2.0 mm, the whole run.** `J6`-`J9` pin 2 all sit at *x* = 106.04 between
     pin 1 (signal) and pin 3 (GND); a 2.0 mm spine straight down that column clears both
     by 0.69 mm against the 0.3 mm `ServoPower` clearance, so every header hangs off one
     2.0 mm conductor and there is no narrower "branch" — the J9→J8 segment carries three
     servos anyway. `C1` moves 1.2 mm and flips so its `VBATT` pad sits *on* the trunk's
     corner instead of in its way.
   - **`GNSS_RF`**: `U8` pin 11 straight to `J5` at 0.36 mm, 2.59 mm long.
   - **`U1` pins 2/3 (`VIN`, `EN`)**: left to the autorouter, `VIN` boxed `R1`'s `EN` pad in
     (the one unrouted link of the first run). `R1` turns 180° and both leave between
     `U1`'s two GND stitch vias as parallel 0.2 mm tracks (0.15 mm clear of each via).
   - **`J4` pins A1/B12 (GND)** are tied on F.Cu to the USB-C shield tab. `layout.py`'s
     stitch via there ended up on an island of `In1`/`In2` once the router's vias
     surrounded it (DRC: "via connected on one layer").
3. **Freerouting 2.4.1**, headless, via Specctra DSN/SES with KiCad's own
   `ExportSpecctraDSN`/`ImportSpecctraSES`. It completes every signal net.
4. **Silkscreen**: every reference re-placed at JLCPCB's 1.0 mm minimum where it overlaps
   no pad, via, other label, other part's silk or other part's *body* (a label under a
   part vanishes on assembly — the first pass put "J10" under the GNSS module). Eight
   0402s in the MCU cluster have no such spot; their silk reference is hidden and they
   are on the assembly drawing (`fab/flight_computer-assembly.pdf`). "+"/"−" marks sit
   beside the `J1` wire pads.

**The 14 DRC warnings that remain are all library-footprint cosmetics, and none is
excluded** (there are still no exclusions in this project): 8 × `lib_footprint_mismatch`
(the embedded copies of stock footprints are older than KiCad 10.0.6's library — no pad
changed), 4 × `silk_over_copper` on `SW1` (the stock TL3342 footprint's own silk crosses
its pads; the plotter clips it), 2 × `silk_edge_clearance` on `J4` (its outline runs to the
edge because the connector is edge-mounted — below).

`scaffold/fab.py` then writes `fab/`: Gerbers + Excellon zip, a JLC BOM and CPL (61 placed
parts; LCSC numbers live in `fab.py`, not in symbol fields, because `gen.py` regenerates
the schematics), an assembly PDF and `ORDERING.md`.

### Things found while finishing it (2026-09-24)

Like the regulator and the magnetometer cap above, several of these change a part:

1. **`J1` could not carry the current.** JST-GH is rated **1 A per contact** (LCSC's own
   listing says so) against `docs/14`'s **4.1 A** all-four-stalled case. Replaced, per Ben,
   by two 1.25 mm-drill wire pads for an **18 AWG XT30 pigtail**: the XT30 (15 A) lives on
   the wire, and the wire rather than the PCB takes the pack lead's pull and vibration.
2. **`C2` "100 µF/25 V" in 1210 does not exist** — 100 µF in 1210 stops at 10 V. Now
   **22 µF/25 V**, the same part as `C1`; at 8.4 V X5R keeps ~12 µF each, so ~25 µF of bulk
   on `VBATT`. If servo transients ever want more, that is a footprint change
   (a polymer tantalum), not a value change.
3. **The `RF` netclass was never in the project file.** `gen.py` defined it, but `gen.py`'s
   `.kicad_pro` template had Python `#` comments *inside the JSON string*, so it could not
   have written a valid file; the `.kicad_pro` on disk predated the RF change, and
   `GNSS_RF` was sitting in `Default` at 0.25 mm (59.9 Ω) the whole time this README said
   0.36. `gen.py` now builds the project JSON from Python tables (`NETCLASSES`,
   `BOARD_RULES`) and the file on disk has been merged to match.
4. **`Power` at 0.6 mm could not enter the fine-pitch pins.** A 0.6 mm track into a 0.3 mm
   LQFP/WSON/LGA pad on 0.5 mm pitch violates clearance to the neighbour. Now 0.3 mm
   (+3V3 is 112 mA, VIN ~60 mA; 0.3 mm is ~1 A on 1 oz), with 0.6/0.3 mm vias.
5. **The USB pair netclass was ~76 Ω, not 90.** 0.4/0.2 mm → **0.25/0.15 mm = 90.9 Ω**
   (`scripts/pcb_placement_report.py` prints both). At 12 Mbit/s over ~25 mm this is
   bookkeeping, not signal integrity.
6. **`J4`'s mouth was 1.1 mm inboard of the edge.** `gen_pcb.py` clamps every courtyard
   inside the outline, so the USB-C receptacle sat at *y* 140.25 with its face at 143.9 —
   a plug's overmold would have hit the PCB edge before seating. `J4` is now `EDGE_MOUNT`
   in `gen_pcb.py`, registered so its body front lands exactly on *y* = 145.0.
7. **Board rules now match JLCPCB's 4-layer capabilities** (via hole to track 0.2 mm,
   min track 0.15 mm because Freerouting necks 0.25 mm tracks to 0.187 at fine-pitch
   pads, silk text ≥ 1.0 mm). They were stricter in places JLC is not (hole clearance
   0.25) and looser where it is (text 0.8 mm).
8. **The power corner is frozen in `layout.py`'s `MANUAL_FIXUP`.** Changing *one* footprint
   (`J1`) reshuffled seven passives through `relax()`, and `finish.py`'s hand-drawn copper
   depends on that geometry. Pinned at the positions that passed DRC and the placement gate.
9. **Placement gate: 2 failures → 1.** Turning `R1` put its `VIN` pad beside `U1`; `C3`
   (3.40 mm vs 2.5) is the one left, accepted as before.

The antenna stays **passive** (`docs/14`) — routing is where "cheapest to make before
layout freezes" expired for the active-antenna option.

### IMU LDO, GNSS via fence, and simulation (2026-09-24, second pass)

- **`U9` LP2985-33** now feeds the ICM-42688-P (`+3V3_IMU`, both supply pins and the CS
  pull-up `R8`), from `VIN` through an **RC pre-filter `R33` 10 Ω + `C30` 1 µF**. The
  usual gyro LDOs (LP5907, TPS7A20) stop at 5.5–6 V in; a full 2S pack is 8.4 V.
  `+3V3` no longer reaches the IMU at all.
- **GNSS via fence**: `finish.py via_fence()` adds GND vias 0.7–1.3 mm either side of
  `GNSS_RF` and round `J5`, each checked against every pad/track/via. Four fit, plus
  the four existing GND-pad vias of `U8` and `J5` around the 2.6 mm run.
- **`scripts/pcb_sim_report.py`** simulates the routed board with KiCad's own bundled
  ngspice (`design/ngspice.py`, nothing to install) and numpy/scipy, from copper read by
  `design/pcb_copper.py`. Output is saved in `out/pcb_sim_report.txt`. Findings:
  1. **Servo stall (4.1 A)**: no brown-out even from a cold, nearly flat pack (VIN ≥ 6.05 V
     against a 2.6 V UVLO); the sag is the pack's internal resistance, the board adds
     ~26 mV. The trunk runs about +11 °C at stall.
  2. **IMU supply noise**: 3.5 mV rms on the old shared `+3V3` → **34 µV rms** (new LP2985
     silicon) / **294 µV rms** (legacy silicon) on `+3V3_IMU` — 40 / 21.5 dB. Without
     `R33` the legacy silicon passed the buck's 1.1 MHz switching ripple *through* the LDO;
     that is why the RC is there.
  3. **Magnetometer — found by the simulation, then fixed with a star ground.** At DC (a
     stall, or servos holding against aero load) a servo return through the GND planes
     spreads by resistance instead of running under the trunk; the loop put **~25 mgauss at
     `U5` at 4.1 A** against the **18.0 mgauss** allowance. The "~0.1 mgauss" in "Planes"
     above assumed the high-frequency return path, which DC does not take.
     **Now:** the servo return is its own net, **`SERVO_GND`** — `J6`-`J9` pin 3, `C1`
     and `J1` pad 2 — drawn by `finish.py route_servo_gnd()` as a 2.0 mm F.Cu column 2.5 mm
     beside the VBATT spine, then on B.Cu directly under the trunk to `J1` pad 2. It meets
     `GND` at exactly one point, **net tie `NT1`** beside `J1` pad 2; logic GND reaches the
     pack through `NT1`, and no servo current enters the planes. **As built: 3.2 mgauss at
     the 4.1 A worst case (18 % of the allowance), ~0.8 mgauss per amp.** Not the ideal
     0.7: the return cannot sit under the spine on B.Cu (the headers' VBATT pins are
     through-hole there) and the pair splits over the last few mm to the two wire pads.
     Servo signals now reference GND across the star: ~40 mV of offset at a full stall,
     irrelevant to 3.3 V PWM.
  4. `+3V3` reaches the MCU's top edge through ~100 mm / ~165 mΩ of autorouted track (the
     shortest-resistance path). ~16 mV DC and ~9 mVpp of load-step noise at 100 mA — fine
     for the MCU, and the reason the IMU is no longer on that rail.
- What these are not: vendor SPICE models. The TPS62162 is modelled from its datasheet's
  power-save equations, the LP2985 from its ripple-rejection figures; every assumption is a
  named constant at the top of the script. Trust ratios and orders of magnitude, not µV.

### Pre-fab audit (2026-09-24, third pass)

- **Pack voltage to the MCU.** Nothing could read the 2S pack. `R34` 100k / `R35` 33k /
  `C33` 100 nF into **PA0** (ADC123_IN0): 8.4 V reads 2.08 V, full scale 13.3 V. `R34` sits
  at `FB1` so no VBATT copper crosses the board; the divided, filtered node does.
- **BOM re-checked on LCSC product pages**: 32 of 39 lines confirmed with stock. `SW1` moved
  to TL3342F160QG (C2886898, 2,200 in stock) — the reel part was out.
- Pins re-read against datasheets where a wrong tie is a dead part: MS5611 PS = GND (SPI).
- `R8` pinned in `MANUAL_FIXUP` — adding parts at the MCU re-rolled `relax()` and threw it
  20.8 mm from U4.

## What is not done

**Routed, simulated, DRC-clean, fab package built. What is left before and after ordering:**

1. **At order time** (`fab/ORDERING.md`): `U4` ICM-42688-P and `L1` are out of stock at LCSC
   (global sourcing / any 2.2 µH 1210 with Isat ≥ 1.2 A); confirm 7 flagged lines in JLC's
   BOM tool; **check every rotation in JLC's placement preview**; select the
   **JLC04161H-7628** stackup.
2. **Height is a mechanical question, not a PCB one.** The four vertical servo headers are
   8.5 mm and a mated servo plug stands ~14-15 mm above the copper — inside the sled's
   18.7 mm half-height per face, but over `docs/14`'s "≤ 8 mm tallest component" and the
   12 mm envelope `avionics.STM32_BOARD` feeds the packing check. Options: accept and update
   the envelope, right-angle headers (needs the header rows turned to exit an edge), or
   solder the servo leads like the XT30 pigtail.
3. **No firmware exists** (memory/`docs/01`: Step 4 is hardware-first). Bring-up needs at
   least: clocks + SWD, each SPI device's WHO_AM_I, the ADC on PA0, TIM4 PWM, GNSS UART.
4. **First-article checks the simulations cannot replace:** scope `+3V3` and `+3V3_IMU`
   ripple; log IMU and magnetometer with the servos stalled vs idle (the star ground's real
   test); verify `J1` polarity before the first pack.
5. No 3D models for `J4`/`U8` (renders show bare pads) — cosmetic.
6. The `.kicad_pcb` is KiCad-10-only format (20260206).

Committed on branch `flight-computer-pcb`. Nothing has been ordered.

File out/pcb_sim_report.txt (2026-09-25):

============================================================================================
4. VBATT TRUNK -- DC drop and heating at the 4.1 A stall, from the routed copper
============================================================================================
  J1 -> J9 pin 2    3.83 mohm of copper    15.7 mV at stall
  J1 -> J8 pin 2    5.55 mohm of copper    21.0 mV at stall
  J1 -> J7 pin 2    7.27 mohm of copper    24.5 mV at stall
  J1 -> J6 pin 2    8.99 mohm of copper    26.3 mV at stall
  hottest segment   2.00 mm carrying 4.10 A -> +10.9 degC (IPC-2221, conservative)

============================================================================================
1. SERVO STALL -- all four stall together at t = 1 ms (ngspice transient)
============================================================================================
  pack                   J6 before   J6 min  VIN before  VIN min   margin to TPS UVLO / LDO dropout
--------------------------------------------------------------------------------------------
  fresh 8.4 V               8.399V   8.236V      8.384V   8.271V   +5.67 V / +4.62 V
  nominal 7.4 V             7.397V   7.153V      7.381V   7.186V   +4.59 V / +3.54 V
  depleted, cold 6.6 V      6.592V   6.019V      6.574V   6.049V   +3.45 V / +2.40 V

  The sag is the PACK's internal resistance, not the board: 4.1 A x the copper above
  is tens of mV.  No brown-out of either regulator in any case, including a cold,
  nearly flat pack.  Servo torque at 6.6 V - sag is the servo's problem, not this board's.

============================================================================================
2. IMU SUPPLY NOISE -- old (shared +3V3) vs new (own LP2985 from VIN), ngspice
============================================================================================

  LP2985 legacy silicon: 45 dB at 1 kHz   |   buck in power-save at 1.12 MHz, 345 mA peaks
                                        OLD: IMU on +3V3     NEW: +3V3_IMU   better by
--------------------------------------------------------------------------------------------
  servo frame + MCU bursts (<50 kHz)          7.047 mVpp        1.610 mVpp     12.8 dB
  regulator switching (MHz)                   0.312 mVpp        0.020 mVpp     23.7 dB
  total rms (+ LDO self-noise)                 2711 uVrms         293 uVrms     19.3 dB
  (for scale: VIN itself swings 148 mVpp with the servos working; +3V3 at the buck 3.6 mVpp switching ripple)

  LP2985 new silicon: 70 dB at 1 kHz   |   buck in power-save at 1.12 MHz, 345 mA peaks
                                        OLD: IMU on +3V3     NEW: +3V3_IMU   better by
--------------------------------------------------------------------------------------------
  servo frame + MCU bursts (<50 kHz)          7.047 mVpp        0.039 mVpp     45.2 dB
  regulator switching (MHz)                   0.312 mVpp        0.001 mVpp     48.5 dB
  total rms (+ LDO self-noise)                 2711 uVrms          34 uVrms     38.0 dB
  (for scale: VIN itself swings 148 mVpp with the servos working; +3V3 at the buck 3.6 mVpp switching ripple)

  The ICM-42688-P datasheet gives no supply-rejection figure, so this is reported as
  volts at the pin, not dps.  What it establishes is the RATIO: the IMU's supply is
  now isolated from both the servo current on the pack and every load on +3V3.

============================================================================================
3. MAGNETOMETER -- field from the board's own VBATT copper + plane return at stall
============================================================================================
  sensor at (162.0, 110.5) mm, 58 mm from the pack pads
  supply copper alone             24.809 mgauss
  IF the return used the planes   25.288 mgauss   (the board before the star ground)
  AS BUILT (SERVO_GND star return)   3.221 mgauss   against the 18.0 mgauss allowance
  compare: ONE untwisted 1 A servo lead 50 mm away = 40 mgauss (docs/14: twist them).
  VERDICT: board copper uses 17.9 % of the magnetometer allowance at the 4.1 A worst
  case -- NOT negligible.  The servo leads, off-board, remain the real risk.
  DC is the worst case for a PLANE return (it spreads by resistance); the star return
  is a trace, so it stays beside/under the trunk at every frequency.

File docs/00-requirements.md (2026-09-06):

# Requirements & Constraints — Canard-Guided High Power Rocket

Status: **DRAFT v0.1**. Every `TBD` is a decision that must close before the airframe
is frozen. Nothing gets ordered until this document has no `TBD` in the "Frozen by"
column for that item.

---

## 1. Mission statement

Demonstrate closed-loop lateral guidance of a high power rocket using forward canards,
including correct handling of canard-induced flow interference on the aft fin set.

### 1.1 Scoping the word "waypoint"

This matters more than any geometry decision, so it goes first.

A rocket under boost and coast has control authority only while it has airspeed, and it
cannot loiter, slow down, or turn around. A "waypoint" in the sense used in UAV work
(fly to a 3-D point, arrive, proceed to the next) is not physically achievable on a
ballistic high power flight. What *is* achievable, in increasing order of difficulty:

| Level | Capability | Notes |
|---|---|---|
| L0 | Passive flight, canards locked at zero | Baseline. Proves airframe + avionics. |
| L1 | **Roll control** — hold roll angle / null roll rate | Single axis, well-posed, the standard first result. This is where the canard/aft-fin interference problem shows up most sharply. |
| L2 | **Attitude hold** — hold commanded pitch/yaw attitude, e.g. vertical | Nulls wind-induced weathercocking. Visibly impressive on video. |
| L3 | **Guidance to a ground target** — bias attitude to steer the impact/apogee point toward a commanded lat/lon | This is the closest honest analogue to "waypoint." Crossrange is limited (the tool in this repo computes how much). |
| L4 | Multi-waypoint path following during ascent | Not physically meaningful for this vehicle class. |

**Recommendation:** define the project as L1 → L2 → L3, with L1 as the minimum
success criterion and L3 as the stretch goal. Frame it as "closed-loop guidance
to a commanded ground target" rather than "waypoints in the air." That is defensible
in a defense, and it is achievable in two semesters.

If you genuinely want multi-waypoint navigation, the standard way to get it is a
**guided recovery** phase: deploy a steerable parafoil at apogee and navigate under
canopy, where you have minutes of flight time instead of seconds. That is a separate
subsystem and arguably a separate project. Decide now; do not try to do both.

### 1.2 Regulatory / range-access constraint — RESOLVE IN WEEK 1

Actively steered rockets sit in a genuinely restricted area, and this can kill the
project outright if discovered late. Before any hardware is purchased, you must
personally confirm all of the following in writing:

- **Club safety codes.** NAR and Tripoli sanctioned launches place restrictions on
  rockets carrying active guidance intended to steer the vehicle toward a target.
  Read the *current* NAR High Power Rocket Safety Code and Tripoli Safety Code
  yourself, then talk to the prefect/RSO of the specific club you intend to fly with.
  Active roll and attitude *stabilization* research projects have flown at research
  launches with prior approval; do not assume, get it approved.
- **FAA.** 14 CFR Part 101 Subpart C governs amateur rockets and the waiver your club
  files. Confirm with the club whether an actively guided vehicle is covered by their
  standing waiver.
- **Export control.** Guided rocket technology can touch ITAR (USML Category IV).
  For a university project this is normally handled by your institution's export
  control / research compliance office. Ask your faculty advisor to loop them in.
- **University IRB/EH&S and advisor sign-off.**

Practical mitigations that keep you clearly inside the lines and are commonly
accepted: (a) authority-limited actuators, so the vehicle physically cannot deviate
far; (b) canards mechanically locked to zero for the first flight; (c) a hard
"disarm on anomaly" that centers and locks the canards; (d) framing and documenting
the work as active stabilization research rather than target guidance; (e) flying at a
site that explicitly permits research/experimental flights (e.g. FAR, or a Tripoli
research launch).

| Action | Owner | Due | Status |
|---|---|---|---|
| Read current NAR + TRA codes, write summary | You | Week 1 | **DONE (Aug 2026)** — file the summary in `docs/` |
| Email club prefect describing the project, get written response | You | Week 1 | **DONE (Aug 2026).** File the written response in `docs/` — it is the evidence, not the email you sent |
| Advisor + export control office contact | You | Week 2 | **DONE (Aug 2026)** — keep the written response on file; it is the first thing a reviewer asks for |

---

## 2. Hard constraints (the things you cannot design around)

| # | Constraint | Value | Source |
|---|---|---|---|
| C1 | Certification level held | TBD (assume none today) | You |
| C2 | Max motor impulse | **L2** (J / K / L; NAR/TRA Level 2 ceiling). The vehicle will not fly an M-class or larger motor | NAR/TRA |
| C3 | Budget ceiling | TBD | You |
| C4 | Calendar: design freeze / build / flight window | TBD | Academic calendar |
| C5 | Field waiver altitude at your site | **No ceiling** (per prefect). Get this in writing — an unlimited ceiling is unusual and normally implies restricted airspace or a special waiver, and the actual document matters for flight cards | Club |
| C5a | Recovery area dimensions | **RESOLVED (Aug 2026): effectively unbounded.** No property boundary within any credible drift radius, so field size no longer sets max apogee and this is no longer the governing constraint. The apogee cap in R6 survives on other grounds | Club |
| C6 | Machining/fab access (lathe, mill, printer, layup) | TBD | Your school |

### 2.1 Certification is a schedule driver, not a formality

To fly a J motor or above you need **Level 2**, which requires holding **Level 1**
first, plus a written exam. Each cert is a separate flight on a separate launch day,
and launch days are weather-dependent and often monthly. Working backward from a
spring flight window, an L1 attempt needs to happen very early in the fall.

Do **not** attempt certification on the guided vehicle. Build a simple, cheap,
throwaway L1/L2 airframe for the cert flights. It is also the best possible avionics
testbed: fly the flight computer as a passive data logger in the cert rocket, so by
the time it flies in the guided vehicle the sensor stack and logging are already
flight-proven.

| Milestone | Target date | Status |
|---|---|---|
| L1 cert flight (H/I motor, simple kit) | TBD — earliest possible | TBD |
| L2 written exam | TBD | TBD |
| L2 cert flight (J motor) | TBD | TBD |
| Guided vehicle flight 1 (canards locked) | TBD | TBD |
| Guided vehicle flight 2 (roll control active) | TBD | TBD |

---

## 3. Derived requirements

These are the numbers the sizing tool in `design/` either consumes or produces.
Values marked *(computed)* are outputs of `scripts/sweep.py` and
`scripts/baseline.py`, not guesses.

| # | Requirement | Target | Rationale |
|---|---|---|---|
| R1 | Static margin, canards at zero, at rail exit | 1.5 – 2.5 cal **nominal**, and P(SM < 1.0) < 1% under mass/CP uncertainty. **Met at 1.94 cal nominal and P = 0.65% with the 60 g of nose ballast the design now carries** — see §7.1 and §7.2 | Below ~1.0 unsafe; above ~3 the vehicle weathercocks hard and fights the controller. The probabilistic half of this requirement is what sized the aft fins — see §7 |
| R2 | Static margin must stay > 1.0 cal with canards at full deflection | *(computed)* | Canards are ahead of the CG and are *destabilizing*; this is the trap in canard design. **"Full deflection" is 9.2°, not 8.0°, since the horizontal freeze — see R13** |
| R3 | Rail exit velocity | ≥ 15 m/s (prefer ≥ 20) | Fin authority at rail exit; standard HPR practice |
| R4 | Thrust-to-weight at ignition | ≥ 5:1 | Standard HPR practice |
| R5 | Max Mach | ≤ 0.8 | Keeps you subsonic. Transonic aero invalidates Barrowman, makes the controller design far harder, and adds no value to a controls project |
| R6 | Apogee — **two-sided since the horizontal freeze** | **Vertical mode ≤ 1600 m (5250 ft) AGL; horizontal mode ≥ 250 m AGL.** The lower bound is new and it is what sets the minimum launch elevation (30°): the main fires at 200 m, so below ~250 m of apogee there is no dual-deploy sequence at all, only a drogue-to-ground descent this vehicle is not sized for. The upper cap does not bind a flat flight at any motor in the 54 mm catalogue (docs/12 §5.6) | **Neither a waiver limit nor a field-size limit** — both are unbounded at this site (C5, C5a). The cap is retained on the three grounds that survive: keeping max Mach under 0.8 with real margin (R5), keeping the manoeuvre visible and filmable from the pad, and holding search time and cost per flight low enough to fly five or six times *with the data intact*. An unbounded field removes the risk of landing off the property; it does not make a rocket easier to find. See `scripts/recovery_study.py` |
| R7 | Internal diameter for actuator bay | Not binding — 4 servos need 79 mm of arc against 188 mm available, 45 mm central void (see §4) | **Superseded.** Diameter is set by the 54 mm motor mount and recovery packing volume, not by the actuators |
| R8 | Commanded lateral acceleration authority early in coast | ≥ 0.5 g | Enough for a measurable, visible correction. Baseline achieves **1.82 g** at 8°, for **400 m** of crossrange |
| R9 | Roll authority | Net Cl_delta must retain correct sign at all conditions, with ≥ 50% of canard-only authority surviving interference | See §5 |
| R10 | Control loop rate | ≥ 100 Hz | Baseline pitch mode is 4.3 Hz, so 100 Hz gives ~23x margin. `baseline.py` derives a ≥87 Hz floor from it |
| R11 | Recovery | Dual deploy: **18 in drogue vertical / 16.1 in horizontal** at apogee, **56 in** main at 200 m (650 ft). **The drogue is sized by its own OPENING SHOCK on a horizontal launch, not by descent rate:** a flat flight reaches apogee at ~94 m/s, not ~1 m/s, because the horizontal velocity never goes away, and an 18 in canopy there makes 2260 N against the 1660 N the M10 anchors, harness and quick links were sized for (docs/10). 16.1 in holds the existing design load and reaches 200 m at 22.6 m/s. 5.0 m/s landing, 50 ft·lbf, 100 s descent. Harness **3/4" tubular nylon, 2 × 3.40 m**, 3.7× on the opening shock after knots, through **quick links** — the webbing does not pass through the U-bolt (docs/10) | Sized by `design/recovery.py`; the main is solved for the landing rate. The drogue was a fixed 18 in until the horizontal freeze made its deployment shock the sizing case. Nothing else in the recovery chain changes — same anchors, same harness, same quick links, same bay. Landing energy is inside the ~75 ft·lbf guidance; confirm the current figure with your prefect |
| R12 | Canards centered + locked on any fault, loss of nav, or after burnout+N s | Mandatory. **NEW: fault-to-centred latency ≤ 0.5 s, and centred unconditionally below 50 m AGL regardless of guidance state** | Safety. The latency is new because a *flat* flight never runs out of dynamic pressure — it reaches the ground with the canards fully effective, so a hardover is dangerous for the whole flight rather than the first third. At 8.13 °/s a one-second lag is 8° of heading, and below 50 m there are 0.75 s and ~101 m/s left. docs/12 §7 |
| R13 | **Canard deflection (NEW)** | **Pitch/yaw ≤ 9.2°; roll command ≤ 2.0°** | Different limits for different reasons and they must not be merged. Pitch/yaw is a STALL limit — 12° local alpha with 1.0° of headroom — and past it the turn rate does not degrade, it collapses below where it started. Roll is the SENSING limit that keeps the rate gyro in range. Raising the pitch/yaw cap leaves `estimation.check_estimation` bit-identical; verified, not argued. docs/12 §5.4 |
| R14 | **Hinge bearing and its seat (NEW)** | **≥ 2.0× at the max dynamic pressure of the profile being flown**, bearing pressure *and* seat crush | **This is the requirement that now caps the design.** A flat flight's max *q* is the burnout value at sea level (15.5 kPa) rather than at 230 m (12.4). Met at **⌀10 journal / 6.0 mm bearing (2.11×)** — the journal has grown twice for this, and length is not available at any diameter, see docs/12 §9 and §11. The SEAT meets 2.0× **only with the printed bay's housing collar bonded in**: 1.74× bare, 11.72× with. **The collar is structure now.** **1.45 cal is the last canard this airframe can actuate**, and it is three checks deep: hinge 2.11×, servo torque 2.07×, root tang 2.02× — not stall and not static margin, which sit at 1.01° of headroom and 0.45% |
| R15 | **Launch elevation (NEW)** | **Horizontal mode 28° above horizontal; vertical mode 5° from vertical** | A true horizontal launch is not available on a T/W of 6.17: gravity droop during boost rotates the velocity vector down ~20°, so a 20° rail is descending by burnout and reaches the ground before the control law starts. 28° is the lowest rail satisfying R6's horizontal floor at the 1.45/1.85 freeze, and it flies flat anyway — 6° of flight path angle at burnout |

---

## 4. Actuator bay — and why it does *not* set the tube diameter

**This section previously argued the opposite, and was wrong.** The correction matters, so
it is documented rather than quietly edited away.

### 4.1 The error

The original argument: for direct-drive canards the servo sits radially with its body
pointing inward, so the servo's *length* consumes tube radius —

    required_ID ≈ 2 × (servo_length + shaft_hub + clearance)

— which ruled out 54 mm and 66 mm airframes, made 75 mm "minimum viable," and left a
packaging margin of only +2.3 mm that drove servo selection for weeks.

That geometry requires the output shaft to sit on the servo's **end** face. **No hobby
servo is built that way.** The output shaft is on a large face, verified against the part
(Aug 2026).

### 4.2 The real arrangement

The servo lies **flat against the inner wall**, output shaft radial, passing through the
wall into the canard root. Its *thickness* consumes radius — 8.0 mm for the KST X08 Plus,
not 23.5 mm. Its *length* runs fore-and-aft along the rocket axis, and only its
*height* has to fit around the circumference:

| Airframe | Inward (old, wrong) | Flat (as built) |
|---|---|---|
| 54 mm | no fit | fits, 21 mm central void |
| 66 mm | no fit | fits, 32 mm central void |
| **75 mm** | +2.3 mm, knife edge | **fits, 45 mm central void** |

Four servos need 79 mm of arc against 188 mm available. **Actuator packaging is not a
binding constraint and never was.** `design/packaging.py` models both; `check_flat_mount()`
is the one describing the vehicle.

This also retires two risks carried for weeks: the mounting-lug clearance question (the
lugs extend the *length* axis, which no longer competes for radius) and the shaft bushing
budget, which now has 45 mm of void to sit in rather than 1.55 mm.

### 4.3 What actually sets the diameter

With actuators out of the way, three things do:

| Constraint | 66 mm | 75 mm |
|---|---|---|
| 54 mm motor mount (57.0 mm OD) | 5.0 mm annulus, 2.5 mm radial | **17.8 mm, 8.9 mm radial** |
| Recovery bay volume for an 18 in drogue + 56 in main | 1.08 L | **1.57 L** against 1.24 L of packed hardware |
| Everything downstream: fin sizing (§7), motor trade, margin robustness, OpenRocket correlation | would all need redoing | **already done** |

**D2 stands at 75 mm, on new grounds.** 66 mm is now theoretically possible where it
previously was not, but a 2.5 mm radial annulus around the motor leaves almost nothing for
centering rings and retention, the recovery packing gets genuinely tight, and the vehicle
does not need to shrink — it meets every requirement with margin. The right response to
"the constraint you thought was binding isn't" is to bank the freedom, not to spend it.

### 4.4 Torque

Torque is unaffected by any of this, and remains the constraint that actually selects the
servo. Peak aerodynamic hinge moment is **0.0577 N·m per panel** at max dynamic pressure
and 8° deflection (`scripts/baseline.py`), with the hinge at 0.20c, forward of the 0.25c
panel CP so the panel is restoring rather than divergent. After a 0.4 derate on stall
torque, against a 2.0× requirement:

| Servo | Length | Thickness | Stall | Torque margin | Verdict |
|---|---|---|---|---|---|
| sub-micro class | 20.0 mm | 8.6 mm | 0.05 N·m | 0.32× | nowhere near |
| micro class | 23.6 mm | 11.6 mm | 0.20 N·m | 1.28× | fails |
| mini class | 22.8 mm | 12.5 mm | 0.25 N·m | 1.60× | fails |
| Hitec HS-5065MG | 23.4 mm | 11.4 mm | 0.219 N·m | 1.40× | fails — the common rocketry pick |
| **KST X08 Plus V6.0** | **23.5 mm** | **8.0 mm** | **0.52 N·m** | **3.60×** | **selected (D4)** |
| MKS HV6100 | 22.5 mm | 10.0 mm | 0.333 N·m | 2.13× | fallback |

Note the Hitec HS-5065MG, the usual choice in hobby rocketry active-control work, misses at
1.40×. Most rocketry servo use is airbrakes and parachute releases — one-shot or lightly
loaded. A canard held against 19 kPa for the whole coast is a harder duty, so the community
answer does not transfer. Capping deflection to about 5.6° at peak q would bring it to
2.0×, which is a legitimate route if availability ever matters.

### 4.5 Mounting

Direct drive, servo bonded or clamped flat into the printed bay, output shaft radial
through a bearing in the tube wall. **Commercial servo frames for this family already do
this** — the Hyperflight SRB-KST-X08 frame and the IDS/LDS kits carry an outboard ball
bearing on the output shaft, which is exactly the load path the canard needs: the bearing
takes the panel bending moment, the servo spline takes only torque.

A bellcrank or pushrod (`check_bellcrank`) also fits, with +33.8 mm to spare, and is the
only way to fit a standard-size servo. It is **not** selected: linkage backlash becomes
deadband in the control loop, and worse, it corrupts GV-2's measurement of `Cm_delta` —
command 8°, the panel reaches 7.2°, and the derivative you publish is wrong. Direct drive
removes that error source. Keep the linkage as the fallback only.

## 5. The canard / aft-fin interference problem

Deflected canards shed a downwash field and a pair of trailing vortices. Those
convect aft and strike the aft fin set, which is what makes canard control
counter-intuitive:

1. **Roll reversal.** Canards deflected differentially to command roll one way induce,
   via their downwash on the aft fins, a roll moment the *other* way. The two partially
   cancel. Depending on geometry, spacing, and interference strength, the *net* roll
   moment can reverse sign — the controller commands right roll and the vehicle rolls
   left, and a naive feedback loop then diverges.
2. **Reduced pitch/yaw effectiveness.** Canard downwash reduces the local angle of
   attack at the aft fins, eroding the moment you thought you had.
3. **Roll-pitch cross-coupling** as the vehicle rolls and the canard plane rotates
   relative to the aft fin plane.

Mitigations, in the order you should consider them:

- **Interdigitate**: place canards at 45° to the aft fins (for 4+4) so the shed
  vortices pass *between* the aft fins rather than onto them. Cheapest and most
  effective fix. Note this makes the aft fins' relative position sensitive to roll
  angle, which is a good argument for closing the roll loop first.
- **Maximize canard-to-fin spacing** so the vortices decay and spread.
- **Keep canard deflection small** and rate-limited; interference grows nonlinearly.
- **Use canards for pitch/yaw only and put roll control on a separate mechanism**
  (or accept roll and de-rotate in software). A legitimate design choice.
- **Identify the sign in flight**: first powered flight does an open-loop deflection
  sweep and logs the response, so you *measure* the sign and magnitude of
  `Cl_delta` and `Cm_delta` rather than trusting a model.

`design/control.py` models items 1 and 2 with an explicit interference factor, and
reports the deflection/geometry region where the net roll moment changes sign.

---

## 6. Open decisions

| # | Decision | Options | Recommendation | Status |
|---|---|---|---|---|
| D1 | Guidance level | L1 / L2 / L3 (§1.1) | L1 min, L3 stretch | TBD |
| D2 | Airframe diameter | 54 / 66 / 75 / 98 mm | **75 mm.** Originally justified by actuator packaging; that argument was wrong (§4.1). Now set by the 54 mm motor mount annulus, recovery packing volume, and the fact that every downstream analysis rests on it. 66 mm became possible once the packaging error was found, and is not worth reopening | RESOLVED, on revised grounds |
| D3 | Canard count | 3 / 4 | **4**, interdigitated at 45° with 4 aft fins (§5) | RESOLVED |
| D4 | Canard actuation | direct-drive / bellcrank | **direct drive**, **KST X08 Plus V6.0** (23.5×8×16.8 mm, 9 g, 5.3 kgf·cm @ 8.4 V); a linkage puts backlash inside the control loop. Fallback **MKS HV6100** (22.5×10×23.5 mm, 10 g) — shorter, so more bushing room, but HV-only and tighter on torque | RESOLVED, pending lug-clearance check against the dimensioned drawing |
| D5 | Aft fin count and size | 3 / 4, semispan 0.95–1.85 cal | **4 panels, semispan 1.70 cal** (was 1.55 until the Sep 2026 agility freeze, §7.2). Set jointly with the canards (D11), not by nominal stability. Larger fins raise static margin but cost authority and push toward roll reversal (§5) | RESOLVED |
| D11 | Canard size | semispan 0.70–1.45 cal | **1.30 cal semispan**, 0.85 cal root, 0.40 taper, **3.6 mm laminate**. Sized jointly with the aft fins (D5) under the probabilistic margin constraint — see §7 and §7.2. Sizing the two sets independently was the original mistake. The range widened from 0.70–1.00 because the original bound was an assumption, not a constraint: `scripts/agility_sweep.py` searched past it and the requirements that actually bind (R1, the root joint, the recovery anchor) all bite well before 1.45 | RESOLVED |
| D10 | Nose ballast provision | none / fixed / adjustable | **Adjustable** threaded rod + washers in the nose shoulder. Lets you set margin after weighing the real vehicle (§7) | RESOLVED |
| D6 | Motor | 103 available 54 mm J/K motors | **AeroTech J401FJ** (1105 N·s, 325 mm case). Re-decided Sep 2026 against **turn rate** rather than crossrange, which reverses the answer: a smaller motor wins, because every requirement that binds (the ±16 g accelerometer, R5, R6, flutter, hinge moment) is triggered by speed and none by static margin except R1. 6.47 °/s and a 1.18 km turn radius against the J449's 4.40 °/s and 2.04 km. Also fits the 332 mm mount tube docs/09 already built. See `02-motor-selection.md` and `11-agility-comparison.md` §7 | RESOLVED |
| D7 | Flight computer | COTS + custom controller board / full custom | **Custom STM32F405 board for the guided vehicle, breakout stack for the cert flights.** Staged deliberately: the cert launches are monthly and the avionics fly as a passive logger in them, so nothing waits eight weeks for a PCB. Deployment stays on an independent commercial altimeter in both stages. See `06-avionics-selection.md` | RESOLVED |
| D8 | State estimation | IMU-only / IMU+baro / IMU+baro+GNSS | **IMU + baro + GNSS + MAGNETOMETER on the board, with the estimator staged by guidance level.** The sensor set cannot stage the way D7's hardware did — everything has to be on the schematic at once — so what stages is the software. The magnetometer is the finding: roll angle is unobservable without one, and L1 (hold roll angle) is the minimum success criterion. Closes without D1. See `07-state-estimation.md` | RESOLVED |
| D9 | Airframe material | cardboard / Blue Tube / fiberglass | fiberglass, at minimum for the canard module | TBD |

### 6.1 Baseline airframe as computed

On the selected **AeroTech J401FJ** (frozen Sep 2026 — see §7.2 and `docs/11` §7; the
Cesaroni J449 it replaced is kept in `02-motor-selection.md` as history).

**This vehicle flies two profiles on one set of parts.** The horizontal freeze
(`docs/12-horizontal-agility.md`, correction 61) changed the deflection cap, the canard
laminate and the hinge journal, and it did NOT change the motor, the fin planforms or the
ballast. Switching between the two is a rail angle and a drogue:

| Item | Value |
|---|---|
| Airframe | 79.4 mm OD (3 in) fiberglass, 2.3 mm wall, 1365 mm long, L/D 17.2 |
| Nose | 4:1 tangent ogive, 318 mm |
| Bays, nose to tail | nav 127 mm, canard module 143 mm, recovery 357 mm, booster 420 mm |
| Avionics location | flight computer, altimeter, GNSS, IMU, battery, BEC in the **nav bay**; telemetry radio and GPS tracker in the **nose** at station 282–318 mm (docs/01 correction 30) |
| Joints | nose/nav **access**, nav/canard **access**, canard/recovery **separation** (main), recovery/booster **separation** (drogue). 1 cal engagement each; a coupler costs bore, not length — `design/joints.py`, docs/01 correction 31 |
| Nose module | Instrumentation, self-contained, one connector. Swappable for a payload up to ~300 g in 469 cm³ (correction 32) |
| Canards | 4 panels, **88.6 root / 8.9 tip** / **115.1 mm semispan (1.45 cal)**, **42.2° LE sweep** — a pointed delta, deliberately NOT matching the aft fins' 30.7° (correction 63) — 45° interdigitated, **4.0 mm laminate (1.0 / 2.0 / 1.0)**. See `docs/12` §13 |
| Aft fins | 4 panels, 151 root / 68 tip / **146.9 mm semispan (1.85 cal)**, 87 mm sweep, 3.2 mm. Grown WITH the canards — they are set jointly or not at all |
| Mass | **6.19 kg dry, 6.70 kg wet** (includes 60 g nose ballast and the 302 g of M10 harness anchors — **still M10 at 3.57× after the 1.45 cal freeze; the self-loading chain converged with no part change**, docs/12 §11) |
| Static margin | **2.06 cal at rail exit, 2.43 cal in coast**; R1 nominal (Monte Carlo median) **2.00 cal**, P(SM < 1.0) **0.34%** |
| Flight, vertical rail | apogee **974 m (3197 ft)**, max Mach **0.413**, max q 11.8 kPa, **6.3 g peak axial**, T/W 6.1 |
| Control, vertical rail | **2.14 g** lateral at the 9.2° cap (10.99° local alpha, 1.01° of stall headroom), **8.08 °/s** peak heading rate, **363 m** crossrange over a 9.5 s window |
| Control, **horizontal rail (28°)** | **2.60 g**, **9.76 °/s** peak heading rate at 90° of bank, **893 m** turn radius. `docs/12-horizontal-agility.md` |
| Roll | Cl_delta NET **+24.54 /rad** interdigitated; **608 °/s at the 2° roll cap**, against a ±2000 °/s gyro. `check_estimation` passes and aided roll error is 0.077° (R13) |
| Actuator | KST X08 Plus V6.0, **2.6× vertical / 2.07× on the horizontal profile** at the 9.2° cap. **This is now one of the two tightest margins in the vehicle and there is no bigger servo that fits** (§4.2, docs/12 §11) |
| Hinge | hinge at 0.20c of MAC — forward of the 0.25c panel CP, so restoring at any sweep. **⌀10 journal in a ⌀10/⌀12 × 6.0 plain bearing, 2.6× vertical / 2.11× on the horizontal profile (R14)**; wall bore ⌀12 H7, four of them taking 20% of the net section at the hinge station. The bay's housing collar is **structure**, not optional — bare wall 1.74×, with collar 11.72× |
| Fin flutter | aft fins **2.01×** margin, canards **3.51×** — the canard figure fell with the pointed planform, because flutter takes t/c on the ROOT chord and the root chord grew (§8, docs/12 §13) |
| Recovery packing | fits with **2.2 mm** spare — the tightest margin in the vehicle, see §7.2 |
| Recovery | 100 s descent, ~0.93 km walk at 15 mph wind, 56 in main. Bay 4.5 cal, verified against vendor pack volumes with +13 mm (§4.3) |
| Nose ballast | **60 g at 191 mm from the nose tip**, ~40 g minimum for R1, provision 300 g (§7.1) |
| Margin robustness | P(SM < 1.0) = 0.1% as designed, 0.3% bare; P(SM < 1.4) = 1.7% / 3.9% (`scripts/robustness.py`) |
| OpenRocket correlation | CNa agrees to 0.3%, CP to 0.17 cal (see `03-openrocket-correlation.md`) |

## 7. Static margin robustness

`scripts/robustness.py` runs a Monte Carlo over mass, component position, motor mass and
CP prediction uncertainty. This is the analysis that set **both** fin sizes.

Two results came out of it, and the second one superseded the first.

**First pass — grow the aft fins alone.** The original 1.05 cal aft semispan gave a
*nominal* margin of 0.50 cal and a **90.5% probability of the built vehicle coming out
below 1.0 caliber**, which is not survivable across five or six flights. Growing the aft
semispan alone walks that back, but pays for it in control authority:

| Aft semispan | Nominal SM | P(SM<1.4) | P(SM<1.0) | Relative authority |
|---|---|---|---|---|
| 1.05 cal | 0.69 | 93.0% | 67.4% | 100% |
| 1.15 cal | 0.99 | 76.7% | 38.2% | 73% |
| 1.25 cal | 1.25 | 52.5% | 15.8% | 60% |
| 1.40 cal | 1.58 | 20.3% | 3.0% | 49% |
| 1.55 cal | 1.86 | 5.7% | 0.4% | 43% |

Buying acceptable risk this way costs over two thirds of the lateral authority.

**Second pass — size both fin sets together, and this is the one that set the airframe.**
Sizing them independently was the original mistake. They pull in opposite directions:
canard area buys authority but costs margin, aft area buys margin but costs authority.
Searched *jointly* under the probabilistic margin constraint plus the flutter and servo
torque limits, the answer is to grow **both**, which beats the original airframe on
crossrange and on safety at the same time instead of trading one against the other:

> **The absolute figures in this section and the next predate August 2026**, when the
> dual-deploy altimeter went into `design/mass.py` (docs/01 correction 26). The selected
> point now reads **1.82 g and 390 m**, and `scripts/robustness.py` now picks canard 1.15 /
> aft 1.85 cal rather than 1.00 / 1.70. **The comparisons and the conclusions hold** — every
> row moved the same way — but regenerate with `python scripts/robustness.py` before quoting
> any single number.

| Canard semispan | Aft semispan | Nominal SM | P(SM<1.0) | Lateral g | Crossrange | Flutter | Torque | Verdict |
|---|---|---|---|---|---|---|---|---|
| 0.70 cal | 1.40 cal | 2.00 | 0.5% | 1.57 g | 346 m | 2.22 | 3.6× | ok |
| 0.70 cal | 1.55 cal | 2.28 | 0.1% | 1.45 g | 316 m | 1.96 | 3.7× | ok |
| 0.85 cal | 1.25 cal | 1.38 | 16.4% | 2.36 g | 525 m | 2.56 | 2.5× | risk 16.4% |
| 0.85 cal | 1.40 cal | 1.72 | 3.3% | 2.13 g | 466 m | 2.23 | 2.7× | risk 3.3% |
| **0.85 cal** | **1.55 cal** | **2.00** | **0.5%** | **1.96 g** | **424 m** | **1.97** | **2.8×** | **selected** |
| 0.85 cal | 1.70 cal | 2.23 | 0.1% | 1.83 g | 390 m | 1.77 | 2.9× | ok |
| 0.85 cal | 1.85 cal | 2.43 | 0.0% | 1.72 g | 362 m | 1.60 | 3.0× | ok |
| 1.00 cal | 1.40 cal | 1.46 | 11.7% | 2.74 g | 597 m | 2.24 | 2.1× | risk 11.7% |
| 1.00 cal | 1.55 cal | 1.74 | 2.8% | 2.50 g | 538 m | 1.98 | 2.2× | risk 2.8% |
| *1.00 cal* | *1.70 cal* | *1.98* | *0.6%* | *2.32 g* | *493 m* | *1.78* | *2.3×* | *ok — beats the selected point* |
| *1.00 cal* | *1.85 cal* | *2.19* | *0.1%* | *2.18 g* | *456 m* | *1.61* | *2.4×* | *ok — beats the selected point* |

**Decisions D11 and D5: canard semispan 0.85 cal, aft semispan 1.55 cal.** It satisfies
every constraint — P(SM<1.0) at 0.5% against a 1% limit, flutter 1.97 against 1.5, servo
torque 2.8× against 2.0.

**It is NOT the highest crossrange that does, and this document used to claim it was.**
That claim survived because the table above quoted a subset of rows that happened to
exclude the ones that beat it. Ranking every fully-passing combination:

| | crossrange | |
|---|---|---|
| canard 1.00 / aft 1.70 | **493 m** | passes everything — `robustness.py` picks this as BEST |
| canard 1.00 / aft 1.85 | 456 m | passes everything |
| **canard 0.85 / aft 1.55** | **424 m** | **selected — third, not first** |
| canard 0.85 / aft 1.70 | 390 m | passes everything |
| canard 0.70 / aft 1.40 | 346 m | passes everything |

So `scripts/robustness.py` and this document disagree about the answer, and the script is
the one doing the arithmetic. **The 0.85/1.55 point is retained deliberately, on margin
rather than on authority**: 1.00/1.70 buys 16% more crossrange but spends flutter margin
(1.78 against 1.97) and servo torque margin (2.3× against 2.8×) to get it. The flutter
number is the one to weigh, because §8 reads it as ±25% — published G10 shear modulus spans
3–7 GPa and flutter speed goes as sqrt(G) — so 1.78 nominal has a materially worse tail than
1.97 does. There is also a practical lock-in: the Onshape canard module is built to a
0.85 cal semispan, and growing it means rebuilding that model.

**This is a live decision, not a closed one.** If crossrange turns out to matter for GV-5,
1.00/1.70 is the row to revisit, and the cost is a CAD rebuild plus a thinner flutter tail.
Do not let it stay buried in a table again.

Note the table is computed **with** the 100 g of nose ballast the design now carries; §7.1
explains why that ballast is not optional.

### 7.1 Why the design carries ballast

Without it the selected point sits at **1.2%**, above the 1% limit. The cause is hardware,
not aerodynamics: the mass budget originally carried a 55 g placeholder per servo, and the
real part (KST X08 Plus, 9 g) removed ~180 g from the canard module, which sits *forward*
of the CG.

The 35.4° sweep briefly retired this requirement — swept canards are less destabilising,
and at the old 0.70 taper the bare vehicle sat at 0.7%. Sharpening the taper to 0.40 put
the authority back (CNa 6.34 → 6.55) and with it the destabilising moment, so the bare
vehicle is at 1.2% again and **ballast is required once more**. That round trip is worth
remembering: canard authority and static margin are the same knob viewed from two ends.

There are two ways to buy that back, and they are not equally good:

| | Crossrange | Flutter margin | Reversible after build? |
|---|---|---|---|
| Grow aft fins to 1.70 cal | 390 m | 1.77× | No — cut once |
| **Keep 1.55 cal, add 100 g ballast** | **424 m** | **1.97×** | **Yes — it is a washer stack** |

**Ballast wins.** It preserves flutter margin, costs less crossrange, and — the real
argument — it is the one variable you can still set *after* weighing the finished vehicle.
Fin size is a prediction you commit to at build time; ballast is a measurement you respond
to. Growing the fins to fix a mass estimate would be trading a tunable parameter for a
permanent one.

Ballast at a station 191 mm from the nose tip:

| Ballast | Median SM | 5th pct | P(SM<1.0) | P(SM<1.4) | Authority | R1 |
|---|---|---|---|---|---|---|
| 0 g | 1.86 | 1.23 | 1.21% | 11.3% | 100% | **FAIL** |
| 25 g | 1.90 | 1.26 | 0.93% | 9.9% | ~98% | PASS (minimum) |
| 50 g | 1.93 | 1.30 | 0.73% | 8.3% | 96% | PASS |
| **100 g** | **2.00** | **1.37** | **0.43%** | **5.8%** | **93%** | **PASS — design point** |
| 200 g | 2.13 | 1.51 | 0.14% | 2.6% | 87% | PASS |
| 300 g | 2.26 | 1.64 | 0.04% | 1.1% | 82% | PASS |

**About 25 g is the minimum that satisfies R1; carry 100 g as the design point** and provision
for at least 300 g so you have room to respond to whatever the scale actually says. Note
that authority falls roughly as 1/SM, so ballast is not free — but at 100 g it costs 7% of
a quantity you have 4.7× more of than R8 requires.

**The dominant uncertainty is not any mass line — it is the CP prediction itself**
(±0.35 cal, 1σ, assumed). No amount of ballast or fin area fixes that; only an independent
check does. Two consequences:

1. The OpenRocket cross-check is not a formality, it directly attacks the largest single
   source of risk in the design. Do it before ordering anything.
2. Barrowman is generally *conservative* at low angle of attack (real CP tends to sit aft
   of prediction), so the symmetric error band used here is likely pessimistic on the
   dangerous side. That is the correct direction to be wrong in.

**Also required: a nose ballast provision.** A threaded rod and washer stack in the nose
shoulder. §7.1 above sizes it; this is the hardware note. It converts static margin from a
prediction you are betting the vehicle on into a parameter you measure and set after
weighing the built rocket, and it has just earned its place by absorbing a 180 g change in
the servo line without touching the airframe.

Every number above is an output of `scripts/baseline.py` and will move as the mass budget
is replaced with weighed components.

**The ballast table above is on the OLD 0.85/1.55 airframe.** At 1.30/1.70 the fins
dominate the CP so completely that the whole 0 → 100 g sweep moves median SM only
1.83 → 1.96 cal. 40 g is now the R1 minimum (P = 0.97%, on the edge) and **60 g is the
design point** at 0.65%. Ballast stopped being the cheap margin knob; see §7.2.

### 7.2 The Sep 2026 agility freezes, and what they cost

> **There were TWO, and this section describes the first.** The vertical freeze below
> (J401FJ, 1.30/1.70, 60 g) is unchanged and still the airframe. The **horizontal freeze**
> that followed it (correction 61, `docs/12-horizontal-agility.md`) changed only the
> deflection cap, the canard laminate and the hinge journal, and it repeated this section's
> lesson a third and fourth time: the search was again an upper bound until the structural
> chain had been run on the winning point, and the two constraints it was missing —
> the hinge bearing and the drogue's deployment shock — both failed on the *frozen*
> geometry the moment it was flown flat. `docs/12` §9 is that record.

#### The vertical freeze

`scripts/agility_sweep.py` re-ran the joint fin/motor search against **heading rate**
instead of crossrange, under every requirement at once. The winning point — J401FJ,
canards 1.30 cal, aft 1.70 cal, 60 g ballast — was adopted as the frozen baseline.
`docs/11-agility-comparison.md` §7 carries the search itself and the relaxation ladder.

What the sweep did **not** model, and what it cost when the point was actually applied:

| | before freeze | sweep predicted | as built |
|---|---|---|---|
| peak heading rate | 4.40 °/s | 6.91 °/s | **6.47 °/s** |
| turn radius | 2.04 km | 1.13 km | **1.18 km** |
| lateral g at 8° | 1.41 g | 1.93 g | **1.76 g** |

The 6% shortfall is two structural consequences the search had no check for:

1. **The canard root joint.** A 1.30 cal panel puts 28.8 N through the tang instead of
   21.1, and its CP moves outboard, so bending at the wall *doubles* (0.610 → 1.273 N·m).
   The 0.6 mm skin over the tang slot fell to **1.47×** against the 2.0× used everywhere
   else in this project. Fixed by a **3.6 mm laminate** (0.8 / 2.0 / 0.8 — still three
   stocked G10 sheets), which restores 2.65× and costs 1.93 → 1.88 g.
2. **The recovery anchor is self-loading.** Bigger fins → more mass → more descent weight
   → more opening shock → the U-bolt goes **M8 to M10** and the four anchors go
   **191 → 302 g**. `recovery_hardware.py` had written down that this would happen: *"the
   next thing to gain mass anywhere in this vehicle may push it to M10."* The next thing
   was the canards. It converges in one pass because rod size is discrete (M10 holds at
   3.89×), and it costs another 1.88 → 1.76 g.

Constants that moved with it, all of them checked copies that would otherwise have
drifted: `seal.UBOLT_HOLE_DIAMETER` 8.5 → 10.5 mm, `seal.INTERNAL_CONDUIT_RADIUS`
27.5 → 29.4 mm, `recovery.UBOLT_ENVELOPE_VOLUME` 5.95 → 8.39 cm³, `mass.py`
`harness_anchors` 191 → 302 g.

**What is now tight, in order:**

| item | margin | limit | note |
|---|---|---|---|
| recovery bay packing | **+2.2 mm** | must fit | was +13 mm; the M10 anchors ate it |
| canard root joint skin | **2.65×** | 2.0× | at 3.2 mm it was 1.47× and failed |
| bearing seat crush | **8.6× with the printed collar, 1.9× without** | 2.0× | the no-collar fallback is *gone* — see below |
| R1 P(SM < 1.0) | **0.65%** | 1% | |
| aft fin flutter | 2.19× | 1.5× | |
| servo torque | 3.3× | 2.0× | |
| peak axial | 6.5 g | ±16 g IMU | |

**The bearing seat deserves its own line.** `scripts/baseline.py` prices it with *no
collar* — the 2.3 mm G10 wall holding the bearing alone — and on the old airframe that
came out at 3.83×, so the printed bay's collar was a bonus. It is now **1.90×**, under the
requirement. The vehicle still passes because the collar exists and delivers an effective
4.918 mm seat (`design/bay.py`), giving 8.6×. But the freeze converted the collar from a
nice-to-have into **load-bearing structure**: if the PETG-CF collar underperforms, there is
no longer a compliant fallback. That is a genuine reduction in robustness, not a number.

**Not yet closed: the canard module CAD inertia.** `control.CANARD_MODULE_CAD` is an
Onshape measurement of the *0.85 cal* module. Four 1.30 cal panels carry +641 kg·mm² of
roll inertia against a recorded module total of 673 — the tensor understates module roll
inertia by roughly **95%** and its mass by 54 g. Roll is the axis this vehicle flies and
roll inertia sets the bandwidth every gain is scheduled against.
`control.check_measured_geometry()` now detects this and `configure.evaluate()` raises it
as a warning, but **the fix is to rebuild the module in Fusion and re-read the tensor over
the API** — arithmetic cannot repair a measurement.

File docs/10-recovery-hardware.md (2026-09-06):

# Recovery hardware — the U-bolt, its backing plate and the charge well

Added September 2026. Model in `design/recovery_hardware.py`, argument in
`out/recovery_hardware_report.txt` (regenerate with
`python scripts/recovery_hardware_report.py --write`), verdict carried by
`scripts/baseline.py`, geometry by `scripts/make_recovery_hardware_cad_fusion.py`. Full
history in `docs/01-next-steps.md` correction 54.

The U-bolt **holes** have been in the CAD since correction 50, drilled from
`seal.hole_layout()`'s own positions. The hardware standing proud of them had never been
sized. Three scripts said so in their own docstrings and one was blunt about which one
mattered — `scripts/make_bulkhead_cad.py`: *"The backing plate is the one that matters — it
is STRUCTURE — and it is not here, so this part is not yet the whole harness anchor."*

## The headline: a U-bolt used as an anchor is not loaded the way a U-bolt is rated

**`design/seal.py` had carried this sentence since it was written, and it read as a
calculation:**

> "An M5 U-bolt on a 25 mm leg spacing is the ordinary size for this load — 1.3 kN through
> two 5 mm legs is 33 MPa of shear in stainless, which is nothing."

Two errors, and they compound.

1. **The legs are not in shear.** The harness pulls along the bolt's axis, away from the
   plate. The legs are in **tension** and the nuts react it. Shear never enters.
2. **The legs are not what breaks.** The **crown** is, in bending, at the two bends where it
   meets the legs — which is exactly where a U-bolt used as an anchor is observed to
   straighten. A published U-bolt load rating is for **clamping a pipe**, where the crown
   bears on the pipe and the legs really are in tension and nothing bends. That rating
   describes a different structure.

## What it carries

One load, four anchors: **1506 N**, the main's infinite-mass opening shock, which
`design/configure.py` already uses for the harness. One load, three parts, no chance of them
disagreeing.

| Mode | Stress | Margin |
|---|---|---|
| Crown, fixed-arch model (**design case**) | 119 MPa | **2.01×** |
| Crown, straight-beam idealisation | 187 MPa | 1.28× |
| Legs, **tension** (not shear) | 21 MPa | 11.7× |
| Backing plate, own bending | 53.9 MPa | 9× |
| Backing plate, bearing under the nut washers | 3.5 MPa | 107× |

**The straight-beam row does not clear 2.0× and that is left visible.** The arch model is the
right one — a curved crown carries most of the pull in direct tension along the rod, which is
why U-bolts work at all — and a straight beam is a different structure rather than a bound on
this one. But this is the single most safety-critical joint in the vehicle, and what settles
it is a destructive pull test on the actual bolt. That has not been done.

Sized against the mode that governs: **M10, not M5.** The holes already placed in both
bulkheads go from ⌀5.5 to ⌀10.5. They are not drilled yet, so the finding costs nothing but
the drill.

> **M8 → M10 at the Sep 2026 agility freeze.** This file predicted it in as many words —
> *"the next thing to gain mass anywhere in this vehicle may push it to M10"* — and the
> next thing was the canards going to 1.30 cal. More fin → more mass → more descent weight
> → more opening shock (1587.6 N now), and the crown-in-bending margin went under 2.0× at
> M8. The four anchors go 191 → 302 g. See `docs/00-requirements.md` §7.2.

## The part

| Part | Dimensions | Mass |
|---|---|---|
| U-bolt, ×4 | M10 stainless, 25.0 mm leg spacing, crown R 12.5, legs 20.0, rod 79.3 long | 70.87 g |
| Backing plate, ×4 | G-10 39.0 × 24.5 × 3.2, ⌀10.5 holes; two of them relieved | 4.63 g |
| Charge well, main | ⌀12 × 19.00 deep, at R 22.60 on the aft gas seal's aft face | 6.44 g |
| Charge well, drogue | ⌀8 × 20.50 deep, at R 29.40 / 45° on the internal bulkhead's aft face | 6.07 g |
| **Total** | 4 anchors + 2 wells + charges | **205.3 g** |

Both wells sit **on their own charge's lead hole** — the main over a feed-through, the drogue
over the conduit hole — so neither needs a new hole through a pressure boundary. Bore is the
smallest whose well stands no more than 21 mm proud: a deep narrow well is a worse part than
a short fat one, harder to fill, harder to see into, and a lever the canopy can catch on.

**The drogue charge is 0.4515 g and this is the first place it has been printed.**
`seal.internal_bulkhead_from_evaluation()` has computed it since it was written and no report
in this project had ever shown it; `docs/04` lists only the main's.

## Why the backing plate is the one that matters

Its own bending asks for 1.2 mm. What sets it is that it must not **dish** under the nuts,
because if it dishes the footprint the log term assumes is not there.

`seal.Bulkhead.point_load_stress()` goes as log(disc radius / footprint radius). `seal.py`
passed a hardcoded **6.0 mm** there — a bare nut face — and said in a comment that a real
plate would replace it:

| Footprint | Disc stress | Margin |
|---|---|---|
| R 6.00 mm (bare nut) | 96.9 MPa | 4.95× |
| **R 16.71 mm (this plate)** | **60.1 MPa** | **7.98×** |

That is a **result** of the part existing, not a retune. Nothing was softened to get it, and
`seal.py`'s default is unchanged — `SealResult.shock_footprint_radius` is a field a caller
passes — so every previously reported number still reproduces.

## The second finding — the harness does not fit through the U-bolt

`recovery.size_harness()` selects 3/4" tubular nylon: **19.1 mm of webbing.** An M10 U-bolt on
a 25 mm spacing leaves a **17.0 mm clear opening.** Two sized parts of this vehicle, and
nothing had ever put them next to each other.

Opening the U up until the webbing passes needs 21 mm of clear opening, which drives the rod
to M10 and about 310 g of stainless across four anchors — more than the whole motor mount.
That is not the answer.

**The webbing was never meant to pass through it.** `recovery.HARNESS_HARDWARE_KG` has priced
50 g of "links and swivels" since it was written. **Requirement, recorded rather than left as
the thing everybody happens to do: the harness attaches through a quick link, and the link
goes through the U-bolt.** A 6 mm link needs 8 mm of opening, not 21, and there is 9.0 mm to
spare.
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

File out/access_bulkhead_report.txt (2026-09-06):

============================================================================================
WHY THESE TWO WERE NEVER SIZED
============================================================================================

  design/joints.py puts a bulkhead on all four tube-to-tube joints. Two are
  SEPARATION joints and design/seal.py sizes both. The other two are ACCESS joints
  -- come apart by hand or by screws, not on an ejection charge -- and seal.py has
  carried a note since it was written that it does not size either of them. Both
  already spend bay length in joints.budgets() as a 12 mm allowance, so they were
  priced while not existing as parts. Neither is in the CAD, which is why the
  forward wiring pass-through has never been drawn -- the plate it passes through
  was not there.
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

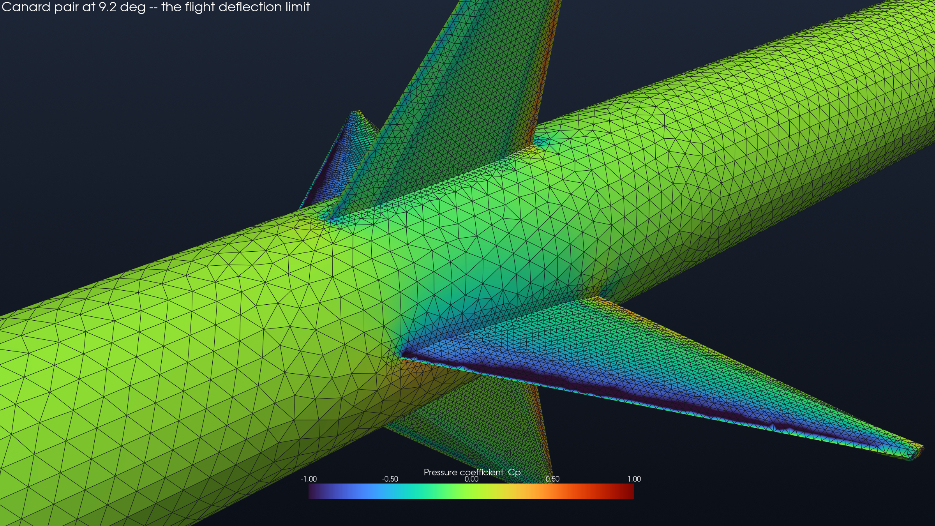
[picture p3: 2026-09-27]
out/cfd/renders/05_trim9_canard_closeup.png

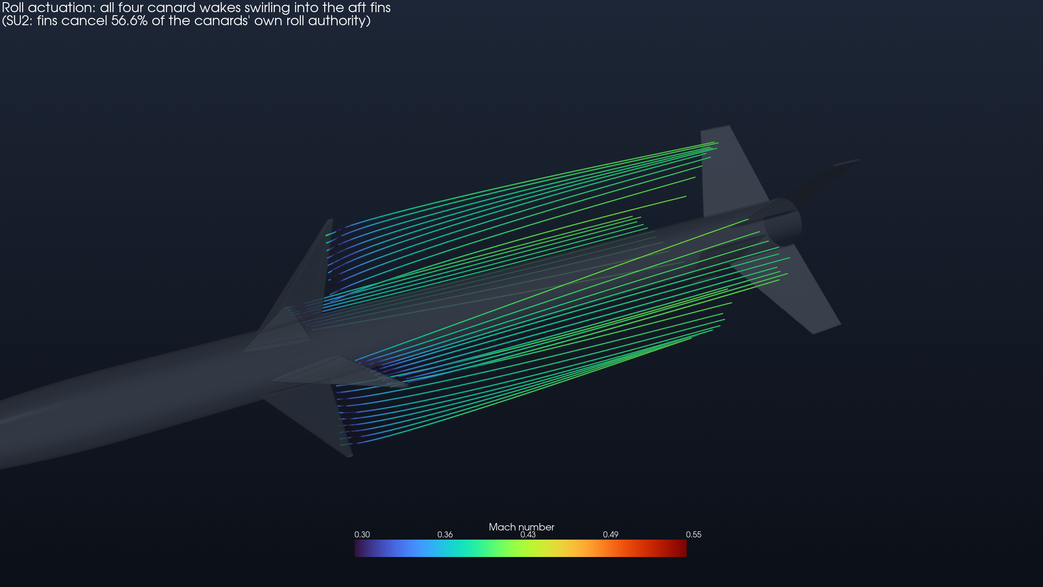
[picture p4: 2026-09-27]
out/cfd/renders/08_roll5_wake.png

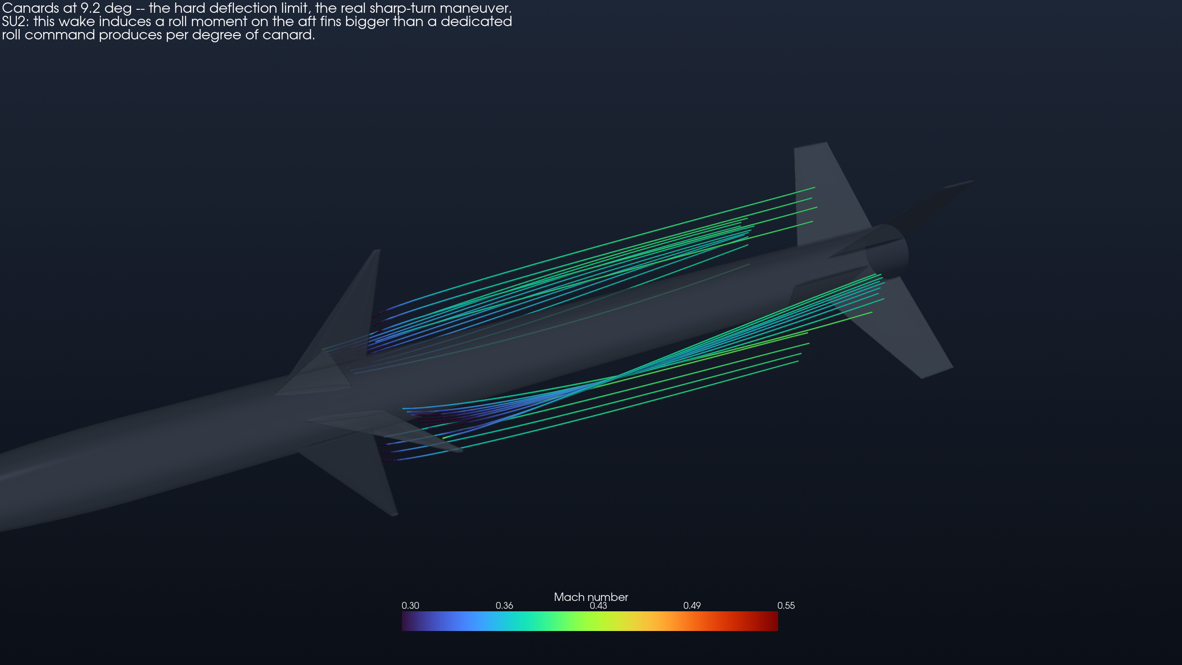
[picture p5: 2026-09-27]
out/cfd/renders/06_wake_streamlines.png

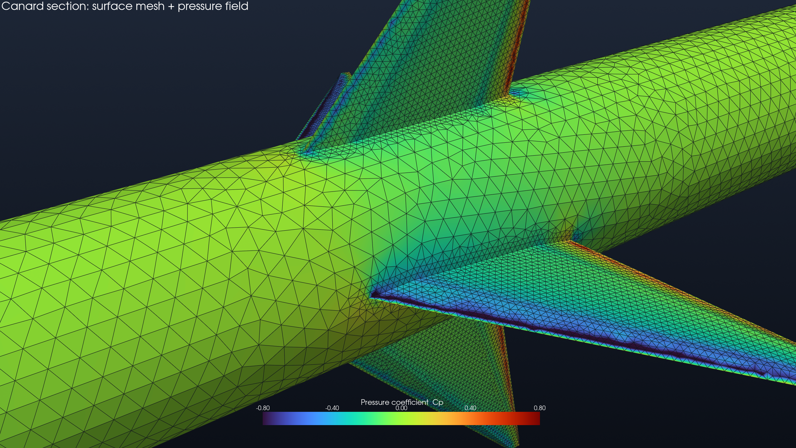
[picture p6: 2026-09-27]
out/cfd/renders/02_canard_closeup.png

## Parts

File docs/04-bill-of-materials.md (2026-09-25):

# Bill of materials

Shareable version: https://claude.ai/code/artifact/9ab713c4-d227-4edb-b377-f45deb504bc2

Vehicle as frozen in `design/configure.py`. Masses are the model's, not weighed — every
line is a prediction until the part is on a scale, and `scripts/robustness.py` should be
rerun as each one is retired.

**Price confidence is marked.** ✅ = researched, vendor and figure cited below. ~ = typical
HPR component pricing, verify at order. Prices are USD, exclude shipping and hazmat, and
were gathered August 2026.

---

## 1. Airframe

| Item | Spec | Qty | Mass | Price | |
|---|---|---|---|---|---|
| Body tube, G12 fiberglass | 3 in, 79.4 mm OD / 74.8 mm ID, 2.3 mm wall. Need 1043 mm; buy one 48 in (1219 mm) length | 1 | 1.075 kg | ~$130 | |
| Nose cone, fiberglass | 3 in, 4:1 tangent ogive, 318 mm, **1 cal hollow shoulder** — its bore is usable nav bay, see `design/joints.py`. **Drawn in CAD** (docs/01 correction 43); real volume is 0.293 kg, not the 0.180 kg wetted-area estimate this line quoted until Sep 2026 — the estimate never counted the shoulder | 1 | 0.293 kg | ~$75 | the instrumentation module; meant to come off |
| Coupler tube, fiberglass | 3 in, for 3 bay joints | 1 length | in structure | ~$50 | |
| Bulkheads and centering rings | G10, 3 in. Sheet stock for the aft gas seal, internal bulkhead, booster forward bulkhead, 2 centering rings, 4 backing plates and both access plates — all sized, none budgeted | set | 0.300 kg | ~$35 | the centering rings are in the propulsion section now; this line is the sheet |

Bay lengths, nose to tail: nav 127 mm, canard module 143 mm, recovery 357 mm, booster
416 mm. Total airframe length 1361 mm.

## 2. Fins

| Item | Spec | Qty | Mass | Price | |
|---|---|---|---|---|---|
| G10 sheet, 1/8 in (3.2 mm) | Aft fin blanks 151 × **147** mm each, plus through-wall tabs. One 12 × 24 in sheet covers the aft set | 1 | 0.385 kg | ~$45 | **1.85 cal semispan** since correction 62 (1.55 → 1.70 → 1.85) — the blanks have grown twice, check sheet yield before ordering |
| G10 sheet, laminate | Canard blanks **114 × 115 mm** each (pointed delta, correction 63 — the blank is the swept bounding box, not the chord) — no longer cut from aft-fin offcuts, they are too big. See the **1.0 / 2.0 / 1.0** stack below | — | 0.170 kg | — | **1.45 cal semispan** since correction 62; **4.0 mm total** since correction 61 |

Aft fins: 4 panels, root 150.9 / tip 67.9 / **semispan 135.0 mm**, 87.3 mm sweep,
through-wall mounted. Canards: 4 panels, root 67.5 / tip 27.0 / **semispan 103.2 mm**,
**66.8 mm sweep (32.9°)**,
interdigitated 45° from the aft fins. Both sets carry the same 35.4° leading-edge sweep.
Flutter margins 1.97× and 4.46×.

## 3. Propulsion

| Item | Spec | Qty | Mass | Price | |
|---|---|---|---|---|---|
| ~~Cesaroni Pro54 3-grain casing~~ **AeroTech 54 mm casing** | For the J401FJ, 325 mm case | 1 | 0.401 kg | **price TBC** | **motor changed Sep 2026 — docs/02 banner.** Casing and reload prices below are the superseded Cesaroni ones and must be re-quoted |
| **AeroTech J401FJ reload** | 1105 N·s, 325 mm, 0.511 kg propellant | 1 | 0.511 kg prop | **price TBC** | replaces the Cesaroni 1261J449-15A. Fits the 332 mm mount tube already sized in docs/09 |
| Motor mount tube | 54 mm ID 54.5 / OD 57.1, **1.3 mm wall, 332 mm long** | 1 | 0.140 kg | ~$25 | **sized, not budgeted** — docs/09. 332 mm reconciles `make_ork.py`'s 331 against this table's own 416, which was the booster's length copied by mistake |
| Centering rings | G-10 3.2 mm, ⌀74.8 / 57.1; **the aft one is SLOTTED** 4 × 3.2 × 8.85 mm for the fin tabs | 2 | 0.021 kg | ~$10 | they are **not** thrust structure — thrust enters at the booster's forward bulkhead |
| Booster forward bulkhead | **G-10 4.8 mm**, ⌀74.8, 3 holes | 1 | 0.039 kg | ~$15 | the disc `seal.py` handed to the motor mount: drogue closure, thrust face and drogue U-bolt anchor in one part |
| Motor retainer | 54 mm screw-on (Aeropack or equivalent), base bonded 15 mm on the mount tube OD | 1 | 0.031 kg | ~$45 | |
| **Plugged forward closure** | Pro54, **no ejection charge** | 1 | — | ~$25 | **NOT OPTIONAL.** The motor's own charge fires into a sealed 25.9 cm³ at 10.2 MPa against a disc that lets go at 6.69. docs/09, docs/01 correction 53 |

Requires **Level 2 certification**. Budget 5 reloads for the GV-1…GV-5 campaign
(+$546), plus separate cert motors.

## 4. Canard actuation

| Item | Spec | Qty | Mass | Price | |
|---|---|---|---|---|---|
| Servo, KST X08 Plus V6.0 | 23.5 × 8.0 × 16.8 mm, 9 g, 5.3 kgf·cm @ 8.4 V | 4 | 0.036 kg | **$43–55 ea** | ✅ |
| ~~Servo frame with outboard bearing~~ | **INVESTIGATED AND DROPPED, Aug 2026.** See the note below — it does not do what this line used to claim, and it probably does not fit | 0 | — | — | ❌ |
| Canard hinge shaft | **⌀10** (⌀6 → ⌀8 at correction 61, ⌀8 → ⌀10 at correction 62) **6061-T6** rod, 32.2 mm long, one end milled to a **1.8 × 11.9 × 25.5 mm blade**. The only custom-machined part in the module | 4 | in shafts | stock rod ~$10 | |
| ~~Servo horn, ⌀4 mm 15T~~ | **INVESTIGATED AND DROPPED, Aug 2026. It does not fit.** There is 0.515 mm between the servo's output face and the bearing, and outboard of that everything passes down the journal. Every female-spline part sold is ⌀7 or bigger. **Correction 61 took the journal to ⌀8, so the DIAMETER objection is gone — the 0.515 mm axial gap, which is what it actually failed on, is not.** Still dropped. See the note below | 0 | — | — | ❌ |
| Anaerobic retaining compound | **Loctite 638 class**, plus the matching activator/primer. This is the coupling: a ⌀4.100 × 3.20 drilled socket in the shaft, filled and pushed onto the spline, so the compound cures in the tooth valleys and *becomes* the female spline. Releases at ~250 °C, which is what makes a servo swappable | 1 bottle | in shafts | ~$20 | ✅ |
| Canard hinge bearing | **⌀10 / ⌀12 × 6.0 plain sleeve, iglidur G class** (⌀6/⌀8 originally, ⌀8/⌀10 at correction 61). Housing reamed **⌀12 H7** — a standard reamer; the interference comes from the bushing being supplied oversize. This is the part that keeps the panel bending out of the servo | 4 | in shafts | ~$5 ea | |
| **⌀12 H7** chucking reamer | The one piece of tooling this design actually requires. **It has been ⌀8 and ⌀10 in earlier revisions of this file — order the ⌀12.** Reams the tube wall **and the printed collar together, after bonding** — see the build note below | 1 | — | ~$15 | |
| Canard shafts, bushings, hardware | The lines above plus fasteners and epoxy | 4 | 0.240 kg | ~$40 | |
| **G10 sheet, 1.0 mm** | Panel skins. 8 skins, 2 per panel | ~0.3 m² | in canards | ~$25 | **0.6 → 0.8 mm at the Sep 2026 freeze, 0.8 → 1.0 mm at correction 61.** Same mechanism both times — skin stress over the tang slot goes as 1/t² — and the second time it was a horizontal launch's sea-level max *q*, not a bigger panel: 1.93× against 2.0×, now 3.09×. docs/12 §5 |
| **G10 sheet, 2.0 mm** | Panel cores. The tang slot is a gap cut in this sheet, not a slot machined later | ~0.15 m² | in canards | ~$20 | |
| Printed canard bay | **PETG-CF** (plain PETG passes too, at 10.0× instead of 14.5×) — **not PLA**, 8× M2 heat-set inserts. **Carries the bearing housing collar**, 3.700 mm of ⌀12 bore per hinge, **⌀16 boss** since correction 62. **This part is STRUCTURE, not an improvement** — on the horizontal profile the bare wall is 1.74× against 2.0× and the collar takes it to 11.72× (R14). 39 g, one print. Design in `design/bay.py`, CAD by `scripts/make_bay_cad.py` | 1 | in structure | ~$10 | ✅ |
| Printed panel bonding jig | Not a flight part. Holds skin/core/skin and the tang in alignment while the epoxy cures, 4× | 1 | — | ~$3 | |

**Two lines here are load path, not hardware, and buying the wrong thing quietly deletes
them.** The panel makes 0.0599 N·m about the hinge — that is what sizes the servo — and
**25.3 N at a bearing 29 mm away, which is 0.718 N·m of bending.** Without the plain bearing
that moment is carried by a 2.3 mm fibreglass hole and then by the servo's own output shaft:
175 MPa against an 80 MPa allowable, 0.46× where 2.0× is required. The **housing collar in
the printed bay** is the second: it holds 3.700 mm of the 6.0 mm bearing, and without it the
bearing seat runs at 3.4× instead of 14.5×.

**Why the servo frame was dropped.** This line used to read "carries the panel bending
moment off the servo spline", and that was an assumption nobody had checked. The commercial
frames — Hyperflight SRB-KST-X08, the Flightcomp/Servorahmen "third bearing frame", the
Aloft LDS kit — are built for **RC glider linkage**, where a servo swings an arm that pushes
a rod to a control surface. Their "counter bearing" supports that *arm* on the far side of
the case; it does not give you a supported shaft coaxial with the servo output, which is
what a direct-drive canard hinge needs. The third-bearing frame is also **50 × 37 × 9 mm**,
against a servo of 23.5 × 8 × 16.8 — four of those inside a 74.8 mm bore is a packaging
problem on its own. Our ⌀10/⌀12 sleeve in the wall already does the job the frame was
imagined to do, and does it in the right place.

**What the search did turn up, and it is the useful half:** those kits all include a
**splined servo horn** for the X08's ⌀4 mm 15-tooth output. **That paragraph was wrong and
is kept below only as the record; the horn does not fit.** See "The coupling" after it.
Cutting a 15-tooth internal spline into a ⌀6 shaft with a 0.8 mm wall is specialist
broaching; a horn arrives with the spline already on it for a few dollars. And the coupling
only has to carry **torque** — 0.520 N·m at servo stall — because the bearing sits outboard
of it and takes all the bending. So the shaft's inboard end simply bonds to a bought horn,
and the hardest feature on the part disappears.

### The coupling: fifteen keys, cast rather than cut

The horn does not fit, and neither does anything else with a female spline on it. There is
**0.515 mm** between the servo's output face and the bearing's inboard end, and everything
outboard of that has to pass down the **⌀6 journal** that turns in the bearing. Fifteen
teeth on a ⌀4 pitch circle need metal around them, so every horn, hub and adapter sold is
⌀7 or larger. Neither space will take one.

What is true in the paragraph above is that **broaching is the thing to avoid**. So don't
cut teeth — **cast them**:

1. Drill the shaft's inboard end **⌀4.100 × 3.20 deep**. A plain round hole, 0.050 mm on
   the radius over the spline's crests. One drilled feature on a part already being turned.
2. Prime the bore (6061 is a *passive* metal; anaerobics need an activator on it — the
   steel spline cures fine on its own).
3. Fill with retaining compound and push it onto the spline.

The compound cures in the tooth valleys and **becomes** the female spline — fifteen keys,
formed by the very part they have to mate with, so they fit by construction. The socket is
drilled 0.30 mm deeper than the spline engages, and that reservoir is not slop: a close
plug pushed into a blind hole full of liquid hydraulic-locks and will not seat.

This is only allowable because **the coupling carries torque and no moment**. The bearing
sits outboard and takes all 0.806 N·m of panel bending; this joint sees 0.520 N·m of servo
stall. An adhesive joint in a bending path would be a bad idea — this is not one.

| | |
|---|---|
| adhesive shear | 6.79 MPa against 17 MPa — **2.50×**, computed as if the socket were smooth |
| the fifteen cast keys | would carry it at 29.9 MPa of bearing — **not counted** in that margin |
| shaft wall in torsion | 15.7 MPa — 10.2× on 6061-T6 |
| serviceable? | yes: releases at ~250 °C, which is the whole reason to use a retaining compound and not epoxy |

**The canard panels are a laminate, not a plate: 0.8 / 2.0 / 0.8 mm G10, bonded, 3.6 mm
total.** The middle sheet is cut away over 12.1 × 25.5 mm at the root, and that gap IS the
tang slot — so the slot never has to be machined. Cutting it into a solid plate instead
would be a 13:1 deep blind cut needing a slitting saw on a mill; as a laminate it is a flat
shape you can cut before bonding. **Order two thicknesses, 0.6 and 2.0.** Both are stocked;
1.8 mm, which an earlier revision specified, is not sold anywhere.

**Two build notes that matter more than any dimension here.**

*Ream the bearing seat after the bay is bonded in, not before.* The bearing needs 6.0 mm of
support and the tube wall is only 2.3 mm of it, so a collar on the printed bay carries the
other 3.700 mm. Those two bores have to be concentric — if they are not, the bearing is
pinched and the hinge binds. Bond the bay in first, then run a **⌀8 H7 reamer through the
wall and the collar in one pass.** Concentricity is then automatic instead of being a
tolerance you have to hold across two parts made by different processes. Print the collar
bore undersize, around ⌀7.5, and let the reamer finish it.

*Bond the panels in a printed jig.* The laminate's whole advantage is that the skin
thickness is set by the sheet rather than by a machine setup — but only if the three layers
and the tang stay put while the epoxy cures. A printed fixture that locates the tang on the
hinge axis at the right chordwise station, and clamps the stack flat, costs an hour of
print time and removes the only real risk in this approach. Keep epoxy off the ⌀6 journal.

Servos mount **flat against the inner wall**, output shaft radial through the wall. Hinge
line at 0.20 of MAC, forward of the 0.25c panel CP so the panel is restoring. Torque margin
3.5× against a peak hinge moment of 0.0599 N·m per panel. Packaging is not binding: 44 mm of
arc needed against 144 mm available — but the **central void is 12 mm, not the 45 mm this
line used to claim**. The servo moved 4.000 mm inboard to make room for the hinge bearing
and every band lost the same 8 mm. The wiring has to fit ⌀12.17 over the 8.2 mm band where
the cable bosses sit. Regenerate with `python scripts/baseline.py`.

## 5. Avionics

Step 4 scope. **D7 and D8 are both closed** (docs/06, docs/07), so the sensor set is
settled even though most envelopes are still estimates.

> **THE CUSTOM BOARD'S LINE BELOW IS SUPERSEDED BY `14-flight-computer-bom.md`
> (correction 64), WHICH IS PART-BY-PART AND DERIVED.** Two corrections to the table as it
> stands, both of which this table's own format hid:
>
> - **The ~$400 is not one number.** It is ~$95 of chips and passives, ~$30 of 4-layer PCB
>   and either hand assembly or ~$120 of low-volume PCBA — **$228 hand-built, $348 with
>   PCBA**, and the split matters because the silicon is FPV-cheap and the process is not.
> - **The "IMU daughterboard ~$30" and "GNSS receiver + antenna ~$40" lines double-count.**
>   On a custom board those parts *are* the board: ICM-42688-P is $8 and MAX-M10S is $30, and
>   both are inside the figure above rather than beside it.
>
> **The servo power BEC is not needed** — the KST X08 Plus is rated DC 3.8–8.4 V and the pack
> is 2S, so the servos run directly off the battery. Reported, not adopted: it is 25 g and a
> line item off a stack that is already checked, so it is a decision, not a correction.

| Item | Qty | Mass | Price | |
|---|---|---|---|---|
| Dual-deploy altimeter — **PerfectFlite StratoLoggerCF** | 1 | **0.011 kg** | ~$70 | 50.8 × 21.3 × 12.7 mm, 20 Hz logging. **Fires the charges; independent of the flight computer in every stage** |
| Flight computer — **custom STM32F405 board** (guided vehicle) | 1 | 0.045 kg | ~$400 | D7 RESOLVED, docs/06. Carries IMU, **magnetometer**, baro, GNSS. 70 × 45 mm is a **layout target**, not a measurement |
| Flight computer — **Teensy 4.1 + breakouts** (L1/L2 cert logger) | 1 | 0.015 kg | ~$40 | 61 × 17.8 mm. Stage 1; also the HIL target and the reference implementation |
| GNSS receiver + antenna | 1 | 0.030 kg | ~$40 | |
| IMU daughterboard | 1 | 0.020 kg | ~$30 | ≥ ±2000 dps gyro, ≥ ±16 g accel, **≥ 1 kHz ODR** — the rate is D8's, and it is not the loop rate |
| **Magnetometer** | 1 | 0.005 kg | ~$5 | **D8, docs/07.** The only sensor that observes roll angle; L1 is defined on roll angle. Keep it off the servo bus |
| Battery, 2S LiPo 1500 mAh | 1 | 0.090 kg | ~$20 | |
| Servo power BEC | 1 | 0.025 kg | ~$15 | |
| Telemetry radio | 1 | 0.045 kg | ~$50 | **in the nose**, station 282–318 mm |
| Independent GPS tracker | 1 | 0.060 kg | ~$100–200 | **in the nose**, with its own battery |
| Wiring, connectors, sled hardware | — | 0.230 kg | ~$60 | |

**Separate the servo supply from the IMU supply.** Four servos slewing on a shared bus next
to a MEMS gyro is a known way to corrupt attitude data.

**This table and `design/mass.py` used to disagree by 60 g, and it was the altimeter**
(docs/01 correction 26). Fixed Aug 2026 by adding `deployment_altimeter` to
`DEFAULT_AVIONICS_BUDGET`; both now total 620 g. It cost 18 m of apogee and 26 m of
crossrange and it *improved* static margin, because the altimeter lands forward of the CG.

**Where all of this physically goes: the nav bay**, 127 mm of 74.8 mm ID at station
318–445 mm, forward of the canard module and behind the nose cone. `configure.py` puts it
there for GNSS sky view and to keep the antenna away from the servo power wiring.

**THE TRACKER AND THE RADIO ARE NOT IN THIS BAY.** As of Aug 2026 they ride in the **nose**,
on the ballast rod at station **282–318 mm** (docs/01 correction 30) — 105 g moved from
station 381 mm to 300 mm. Both are RF parts, neither needs a short wire to the flight
computer, and the nose shoulder is the one place a fibreglass airframe stops shielding an
antenna. An independent tracker with its own battery in its own compartment is what
"independent" is supposed to mean.

**And the nose is a MODULE, meant to come off** (correction 32). After GV-2 the campaign
stops needing telemetry and the same nose can carry a payload: **up to about 300 g with no
other change**, in **469 cm³** between station 200 mm and the nose base. Two build rules
follow and neither is optional if the swap is to be real — **the module carries its own
battery**, and it has **exactly one connector** to the vehicle (the radio's data link; the
tracker needs nothing). The one drawback is RF: the GNSS antenna stays in the nav bay under
the shoulder, so a dense payload sits between it and the sky.

**AND THE BAY FITS — ON THE AREAL MODEL.** `design/avionics.py` is the packing check the
nav bay never had; `python scripts/avionics_report.py` is the argument. It wants **110.4 mm
of sled against 115.0 mm available at a 70.2 mm bore** — so **+4.6 mm**, having been 47 mm
short before the tracker and radio moved to the nose and 9 mm short before D7 closed. *(This
paragraph carried the 9 mm figure until Sep 2026, two corrections after it stopped being
true. The script itself carried a hardcoded "STILL SHORT BY 14 mm" line directly under its
own computed FITS verdict; both are fixed.)*

**BUT THE AREAL MODEL DOES NOT PLACE ANYTHING**, and placing it changes the answer.
`design/sled.py` puts the same stack down as real rectangles on two real faces:
the four boards fit on the 56.16 mm plate `SLED_WIDTH_FRACTION = 0.80` gives, and the
**80 g wiring loom then has nowhere to go** — not on a face, and not in the corner
crescents, which would need it at 1.84 g/cm³. The plate has to reach **59.00 mm**, and
M4 rods allow **59.20 mm**. See `python scripts/sled_report.py`.

Every envelope in that check is an estimate for a part nobody has chosen, so this is a
**warning and not a violation**, and correction 5 is why: an estimate-driven shortfall was
once acted on here and turned out not to be in the hardware. **Measure the loom and count
the conductors before concluding anything** — the 80 g is a line called `wiring_connectors`,
and connectors are not loom.
What the check is sure of is the shape of the problem: a flat sled in a round tube can only
use the rectangle inscribed in the circle, so the binding quantity is footprint on two
faces, not volume — the bay looks two-thirds empty by volume and is not.

Two more things about this bay:

- **The nose shoulder is settled** (docs/01 correction 31). A shoulder is a hollow tube and
  its bore is usable, so it costs *diameter* — 74.8 → 70.2 mm over its 79 mm — and not
  length. The sled runs up inside it, and gets all **115 mm** of usable length at 70.2 mm
  bore. `design/joints.py` models all four joints. *(This bullet said "and the shortfall is
  9 mm" until Sep 2026, three paragraphs under the same section's own **+4.6 mm FITS** —
  the third copy of that stale figure, and the one correction 41 missed while fixing the
  other two.)* Since correction 42 the bore is narrowed over the **whole 127 mm**, not just
  the shoulder's 79: the aft coupler is bonded into the remaining 47.64 mm, which is where
  the static ports are drilled.
- **The firing circuits leave this bay going aft**, cross the canard module, and cross the
  aft gas seal, because there is no room for an av-bay next to the charges. See docs/05.
- **The static ports go here and only here**, 3 × ⌀3.2 mm — and they are now *placed*:
  **station 420.82 mm from the nose tip, clocked 15/135/255°, 4.60 mm deep**, drilled after
  bonding through the airframe tube **and the aft coupler behind it** (docs/01 correction 42,
  `design/ports.py`). That is the only drillable wall in this bay: the nose shoulder occupies
  the forward caliber and its joint comes apart, so a hole there would have to re-align on
  every assembly. The canard module vents through its own wall so that it is *not* part of
  this bay's sensed volume — docs/01 correction 28.
- **The aft coupler is 0.600 cal of bond into the nav bay, not 1.0**, because that is all the
  nose shoulder leaves in a 1.60 cal tube. Its other end — 0.639 cal of engagement into the
  canard module — and the next joint's 0.608 cal anchor there are bounded the same way, by
  the printed canard bay sitting mid-tube rather than by convention (docs/01 correction 42);
  all three fit, with 43.9 mm to spare in the canard module's own tube. All three are below
  the 1.0 cal convention, and **nothing in this project sizes a coupler in bending**, so that
  stays an open item rather than a checked one — the capacity does not. The forward coupler's
  retaining screws are not placed and will want the same 47.64 mm band the ports are in.

## 6. Recovery

| Item | Spec | Qty | Mass | Price | |
|---|---|---|---|---|---|
| Drogue parachute | 18 in, deployed at apogee | 1 | 0.070 kg | ~$35 | |
| Main parachute | **56 in** solved; buy the Fruity Chutes Iris Ultra 60" Compact (nearest real size, lands slower). 193 g, 38.2 cu in packed | 1 | 0.280 kg budgeted | ~$110 | |
| Shock cord, quick links, swivels | **3/4" tubular nylon, 2 × 3.40 m** (2500 lbf) + links/swivels | set | **0.186 kg** | ~$50 | **sized, not budgeted** — 3.7× on the 1.51 kN opening shock after a knot derating. 1" nylon costs a quarter of the bay. Kevlar packs smaller but does not stretch: use a Kevlar **leader** at the charge end, not a Kevlar harness. docs/01 correction 33 |
| Nomex protectors | | 2 | 0.070 kg | ~$30 | |
| Ejection charge hardware, shear pins | | set | 0.060 kg | ~$25 | |

### Deployment hardware — the aft gas seal

Sized Aug 2026; `design/seal.py`, argument in `out/seal_report.txt`, docs/05.

| Item | Spec | Qty | Mass | Price | |
|---|---|---|---|---|---|
| Aft gas seal disc | **G-10 sheet, 4.8 mm**, cut to 74.8 mm | 1 | 0.039 kg | ~$15 | thickness set by the wire hole, not the plate |
| Internal bulkhead disc | **G-10 sheet, 4.8 mm**, 1 × ⌀6 mm conduit feed-through at **R 29.4 / 45°** | 1 | 0.039 kg | ~$15 | no shear pins protect this one; it anchors a harness BOTH ways, so its two U-bolts clock 90° apart and its conduit radius is set by the backing plates, not by the stress field |
| Harness U-bolt | **M10 stainless**, 25 mm leg spacing, crown R 12.5 | 4 | 0.284 kg | ~$50 | **NOT M5, and no longer M8** — the Sep 2026 fin freeze added descent mass, which raised opening shock, which took the crown-in-bending margin under 2.0× at M8. docs/00 §7.2, docs/10 |
| Backing plate | **G-10 39.0 × 24.5 × 3.2**, ⌀10.5 holes; **the two on the internal bulkhead are relieved** 11.5 × 5.5 mm | 4 | 0.018 kg | ~$8 | takes the disc's U-bolt margin 4.90× → 8.09×. It is structure, and this is the part three CAD scripts refused to draw |
| Quick links | **8 mm** stainless, harness to U-bolt | 4 | in harness | ~$18 | **required, not optional** — 19.1 mm of webbing does not pass through the M10 bolt's 15.0 mm opening either. docs/10 |
| Charge well + 2-pole terminal block | Bulkhead-mount, fired face. Main **⌀12 × 19.0** at R 22.6; drogue **⌀8 × 20.5** at R 27.5 / 45° | 2 | 0.013 kg | ~$10 | each sits over its own charge's lead hole, so neither needs a new hole in a pressure boundary |
| Shear pins | **3 × 2-56 nylon** per separation joint | pack | — | ~$6 | the intended fuse; buy spares, they are consumed |
| High-temp RTV, potting | 315 °C service, **forward face only** | 1 | — | ~$10 | |
| Wiring conduit | ⌀5 mm thin-wall, ~240 mm, drogue circuit through the main compartment | 1 | 0.010 kg | ~$5 | costs 1.2 mm of the bay's margin, which is **+4.6 mm** after docs/01 correction 54 |
| Black powder | **1.14 g** main and **0.45 g** drogue, sized at a 2.0× separation factor | — | — | ~$20 | **ground test twice; the calculation is not the arbiter** |

Descent 100 s, landing 5.0 m/s at 50 ft·lbf, ~0.93 km walk in a 15 mph wind. Ground-test
ejection charges twice before flying.

## 7. Ballast — required, not optional

| Item | Spec | Qty | Mass | Price | |
|---|---|---|---|---|---|
| Steel washers, 25 × 6.5 mm | Stack at 191 mm from the tip, sized to the 100 g design point (`design/nose_module.py`) | ~28 | 0.100 kg | ~$10 | adjustable — this is the tuning knob |
| M6 threaded rod, ~150 mm, + nut | Carries the washer stack, captured at the nose plate. **Drawn in CAD, correction 43** — real hardware, not previously counted anywhere | 1 | 0.034 kg | ~$5 | |

Without ballast P(SM < 1.0) is 1.2% against R1's 1% limit. About 25 g of washers is the
minimum that satisfies R1; 100 g brings it to 0.1% (`scripts/robustness.py`). The washer
mass is the last free parameter — set it after weighing the built vehicle, not before. The
rod itself is not adjustable and its 34 g is now counted separately in mass reconciliation
below, having never been counted before Sep 2026. See `00-requirements.md` §7.1.

## 8. Consumables

| Item | Qty | Mass | Price |
|---|---|---|---|
| Epoxy, fillets, tip-to-tip if used | — | 0.200 kg | ~$50 |
| Rail buttons, fasteners, shear pins | set | 0.060 kg | ~$25 |

---

## Budget summary

| Group | Cost |
|---|---|
| Airframe | ~$290 |
| Fins | ~$45 |
| Propulsion (case + 1 reload + mount + retainer) | ~$305 |
| Canard actuation | ~$310 |
| Avionics | ~$525 |
| Recovery | ~$260 |
| Ballast and consumables | ~$90 |
| **One complete guided vehicle** | **~$1,825** |
| 4 further reloads for GV-2…GV-5 | +$546 |
| L1 / L2 cert airframe and motors | +~$300 |
| **Full campaign** | **~$2,670** |

Excludes shipping, hazmat fees on motors, and any spare vehicle. The single largest line is
avionics. **D7 and D8 are both closed** (docs/06, docs/07) and three envelopes are off
datasheets. D8 added one part — a ~$5 magnetometer — so the line did not move, and the
sensor set will not move again on its own. What is still open is that most of these
envelopes and masses are estimates: the number that matters is what a scale says, not what
a decision says. See docs/01 step 5.

## Mass reconciliation

Model dry mass **5.676 kg**, wet **6.300 kg** including 100 g ballast and 0.516 kg of
contingency (10%, carried deliberately — every real build comes out heavy). Both figures
moved +156 g in Sep 2026 (correction 43): the nose cone is a real drawn part now, and its
true volume — including the integral shoulder, never counted before — replaced a
wetted-area estimate. Weigh each part as it
arrives, replace the estimate in `design/mass.py`, and rerun `scripts/robustness.py`. Every
guess retired shrinks the static margin distribution, and the ballast is what you adjust in
response.

## Before ordering

- Confirm the KST X08 Plus mounting scheme against the servo frame — the stock lugs extend
  the length axis and the body is bonded or clamped flat (§4.5).
- Confirm the Pro54 case grain count matches the reload. A 3-grain reload needs a 3-grain
  case.
- Confirm your site permits Blue Streak propellant on the day; sparky and propellant
  restrictions vary by season.
- C3 (budget ceiling) and C4 (calendar) are still TBD in `00-requirements.md`. This document
  is the input to closing C3.

## Sources

Researched prices: [Cesaroni J449-15A reload, CS Rocketry](https://www.csrocketry.com/rocket-motors/cesaroni/motors/pro-54/3g-reloads/cesaroni-j449-15a-blue-streak-rocket-motor.html) · [Cesaroni P54-3G casing, Apogee](https://www.apogeerockets.com/Rocket_Motors/Cesaroni_Propellant_Kits/54mm_Motors/3-Grain_Motors/Cesaroni_P54-3G_Blue_Streak_J449) · [KST X08 Plus, Hobby Club $42.95](https://www.hobbyclub.com/index.php?main_page=product_info&products_id=1828) · [KST X08 Plus, MPI Hobby $55.00](https://mpihobby.com/products/kst-x08-plus-digital-servo-8-4v-0-09s-5-3kg-cm-73oz-in) · [Servo frame with outboard bearing, Hyperflight](https://www.hyperflight.co.uk/products.asp?code=SRB-KST-X08)

Airframe and recovery vendors to price against: [Wildman Rocketry](https://wildmanrocketry.com/collections/fiberglass-1), [Mach 1 Rocketry](https://www.mach1rocketry.com/fiberglass-tubes), [Apogee Components](https://www.apogeerockets.com).

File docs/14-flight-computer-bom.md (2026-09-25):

# 14. The Stage 2 flight computer — what to order, and the three things nobody had checked

Model: `design/flight_computer.py`. Regenerate with `python scripts/flight_computer_report.py
--write` (output `out/flight_computer.txt`); the verdict is carried by `scripts/baseline.py`
so it cannot silently regress. Sensor error terms come from `design/estimation.py` (D8) and
the architecture decision from `docs/06` (D7). Nothing here is typed twice: every rate,
duration and load is computed from `configure.evaluate()`, and every part number is a
datasheet value with the source in its note. This document IS correction 64 — like 61–63 it
lives in its own topic file, with the summary in `docs/01`'s state-of-play block rather than
in that file's numbered list, which ends at 60.

## The headline: the board was selected two documents ago and could not be ordered

`docs/06` chose a custom STM32F405 board with the ejection charges left on an independent
commercial altimeter. `docs/07` named its sensors. Between them they left three gaps, and
none of them was visible from either document:

1. **A gyro requirement no real part satisfied.** `docs/06` asked for selectable full scale
   to ±4000 °/s. The named part tops out at ±2000, and the only ±4000 entry in the code was
   an estimate with no part number — `design/estimation.py`'s own rule ("a requirement you
   cannot buy a part against is not a requirement") broken inside `design/estimation.py`.
2. **No power budget anywhere in this project.** The battery was a line in `mass.py` with a
   capacity and a mass and nothing else. The servos were modelled for torque and speed only.
   Nothing had ever asked whether the pack covers a flight.
3. **Logging had never been turned into bytes.** `avionics.board_requirements()` asks for
   "≥ 100 Hz for 150 s" and its own slack note says "onboard flash is enough."

All three are closed below. Two of them changed a part.

## The BOM

One board, one spin. Prices are order-of-magnitude in ones, not quotes.

| item | MPN | package | interface | qty | USD |
|---|---|---|---|---|---|
| MCU | STM32F405RGT6 | LQFP64 | — | 1 | 10 |
| IMU | ICM-42688-P | LGA-14, 2.5 × 3.0 mm | SPI1, CS1 | 1 | 8 |
| magnetometer | MMC5983MA | LGA-16, 3.0 × 3.0 mm | SPI2, CS2 | 1 | 5 |
| barometer | MS5611-01BA03 | QFN-8, 5.0 × 3.0 mm | SPI2, CS3 | 1 | 10 |
| GNSS receiver | MAX-M10S | LCC, 9.7 × 10.1 mm | USART1 | 1 | 30 |
| log flash | W25Q128JVSIQ | SOIC-8 | SPI3, CS4 | 1 | 2 |
| 3.3 V regulator | TPS62162DSGT | SON-8 | 2S in | 1 | 2.50 |
| GNSS antenna | **passive** patch, u.FL — see note | ~25 × 25 mm | RF | 1 | 8 ~ |
| passives, connectors, LEDs, SWD | assorted | 0402/0603 | — | 1 | 20 ~ |
| PCB, 4-layer, ENIG | 70 × 45 mm, 1.6 mm | — | — | 1 | 30 ~ |
| **deployment altimeter** | PerfectFlite StratoLoggerCF | 50.8 × 21.3 × 12.7 mm | **off-board** | 1 | 70 |
| battery | 2S LiPo 1500 mAh | 70 × 35 × 15 mm | **XT30** (board: 18 AWG pigtail) | 1 | 20 ~ |
| spare IMU + magnetometer | ICM-42688-P, MMC5983MA | — | — | 1 ea | 13 |

`~` = estimated price. Optional and **not flight hardware**: a NUCLEO-F446RE or a WeAct F405
"Blackpill", ~$15, purely somewhere to write and single-step the SPI drivers, the scheduler
and the R12 latch before the board exists. Same core family, so the drivers port.

Four layers, not two: a solid ground plane under the IMU and a separate return for the servo
current are the two things that keep this board's own noise out of its own sensors, and
`docs/01`'s "things that will bite you" already names servo noise into the IMU.

## The first finding — the ±4000 dps requirement is dropped, not bought

`docs/06`'s open item said to specify a part with selectable full scale to ±4000 °/s and run
it at ±2000, on the grounds that "the option is free before layout and unbuildable after."
The option is real — **TDK's ICM-45686 does ±4000 dps and ±32 g for about the same money** —
and it is still the wrong buy. Three reasons, in order of weight:

- **The roll cap is locked and it is what keeps the part in range.** R13's
  `ROLL_COMMAND_CAP_DEG = 2.0` puts steady roll at **566 °/s, 28% of ±2000** — 3.5× of
  margin at every *commanded* operating point.
- **Range does not license lifting the cap, and correction 58 already proved it.** 7.94°
  capped against 62.89° uncapped, both dominated by gyro scale factor at roll rate. The roll
  rate that saturates the part is the same one that drives the dominant error term, so a
  wider part flown uncapped is about **8× worse**. L1 is *hold roll angle*.
- **The only thing that saturates ±2000 is a fault, and a fault is detectable.** Uncapped
  roll is 2602 °/s — 130% of full scale — and it only happens if something runs the canards
  to the stops, which R13 forbids as a command. A gyro pegged at full scale is a *readable
  condition*. **Wiring FS saturation into the R12 latch turns the one scenario the extra
  range was for into a detected fault that centres the canards inside 0.5 s.** That is
  strictly better than measuring the fault accurately while flying it, and it costs nothing.

So the requirement is dropped and the cap carries the load it was already carrying.
`estimation.GYRO_WIDE` is gone; `estimation.GYRO_ICM45686` replaces it with the real part's
datasheet numbers, kept so the rejection is against hardware.

**One honest gap, flagged in the code:** the ICM-45686's scale-factor tolerance and
g-sensitivity in that spec are *assumed equal to the ICM-42688-P's and were not read off the
datasheet*. Scale factor is the dominant term in `attitude_error_budget()`, so that spec is
good enough to reject the part on range-usability grounds and not good enough to quote a
computed error from. If the roll cap is ever revisited, read the real number first.

The rest of the sensor set clears comfortably and none of it is tight:

| | required | available | |
|---|---|---|---|
| gyro full scale | 566 °/s at the cap | ±2000 °/s | 3.5× |
| IMU output data rate | 1000 Hz | 32 kHz | 32× |
| accelerometer full scale | 7.1 g peak axial | ±16 g | 2.3× |
| magnetometer ODR | ≥ 100 Hz | 1 kHz | 10× |

## The second finding — there is no BEC, and the battery was never sized by energy

**The KST X08 Plus V6.0 is rated DC 3.8–8.4 V** (KST_0012, 04/2025) and the pack is 2S. The
servos run **directly off the battery**, so `avionics.BEC` — 25 g and a part — is not needed;
"separate supply from the IMU" becomes a separate *feed and filter* off a star point at the
pack, which is a layout rule rather than a component. The same datasheet independently lands
on **1520 µs / 333 Hz**, which is where `board_requirements()`'s 333 Hz came from, and its
signal is 3.3–5.0 V HIGH, so the F405's 3.3 V timer outputs drive it with no level shift.

The budget itself:

| | |
|---|---|
| logic rail, 3.3 V | **112 mA** (MCU 86, flash 15, GNSS 8.5, baro 1, mag 1, IMU 0.9) → 59 mA off the pack |
| four servos, active at the peak hinge moment | **1.03 A** |
| four servos, stalled | **4.0 A** |
| 60 min armed on the pad | **0.73 Wh** |
| whole flight, servos working 9.5 s of it | **0.06 Wh** |
| pack | 11.1 Wh, 8.88 Wh usable at 80% depth |
| **margin** | **11×** |

**Capacity was never the constraint and 92% of the demand is pad time, not flight.** The
flight costs 0.06 Wh out of 8.88 available. What actually sizes the pack is **peak current —
4.1 A with all four servos stalled** — and that is a C-rating, a battery lead and a conductor
question, not a capacity one. It is also the number that sizes the 14 conductors through the
⌀8.0 mm potted pass-through (`design/access_bulkhead.py`), a count this project has carried
since correction 37 and never turned into wire.

A smaller pack is therefore available and worth ~55 g against a nav bay that
`configure.py` already flags as 114 g over budget. Not taken here: it is a real decision with
a scrubbed-launch argument on the other side, and this document's job was to find out whether
the pack works, which it does.

### The margin no torque check in this project could see

The KST datasheet's performance curve carries an **operation-model banding** that no spec
table would have shown: continuous duty only to ~1.2 kgf·cm, "short time < 10 s repeat" to
~4.8, and a red < 1 s / 60 s-cool zone beyond. Against it:

> **Servo torque margin is 2.03× on STALL torque and 1.15× on the datasheet's own CONTINUOUS
> band.** The peak hinge moment is 1.04 kgf·cm and the continuous limit is 1.2.

Both numbers are true and they are about different failure modes — the 2.0× is "can it
push", the 1.15× is "for how long before it gets hot". The control window is 9.5 s against a
10 s short-time rating, so nothing here fails, and the vehicle is inside the band it needs.
But **this is a margin the project has never looked at**, it sits at 1.15× rather than 2×,
and it is read off a chart rather than a table. It belongs on the Step 5 ground-test list:
`docs/01` already calls for "servo step response under representative load" and this is the
reason to instrument current while doing it.

Priced at the **horizontal** flight's dynamic pressure, which is R15's primary mode and the
binding one — a flat flight's max q is ~15.5 kPa against ~12.4 vertical, and hinge moment
goes as q. `scripts/baseline.py` reports the vertical margin (2.5×); the 2.067× that
`configure.py`'s own comment records corresponds to about a 30° rail. At R15's 28° it is
**2.03×**, and at the sweep's 25° search elevation it is **2.001×** — on the requirement, not
above it, which corroborates `docs/01`'s "two margins are now effectively on the line."

## The third finding — "onboard flash is enough" is wrong by 6×

Written out as a channel list rather than as a sentence:

| channel | B/sample | Hz | B/s |
|---|---|---|---|
| raw gyro + accel, 6 × int16 + timestamp | 16 | 1000 | 16 000 |
| magnetometer, 3 × int16 + timestamp | 10 | 100 | 1 000 |
| baro pressure + temperature | 12 | 50 | 600 |
| GNSS position, velocity, fix quality | 36 | 10 | 360 |
| estimator state: quaternion, roll, rate | 24 | 71 | 1 695 |
| control: 4 servo commands, phase, flags | 12 | 71 | 847 |
| **total** | | | **20 502** |

**4.90 MB per flight against 0.79 MB usable on the F405 after a 256 KB firmware allowance —
6.2× short.** The window is a deliberate upper bound (the whole descent priced at the main's
5 m/s when the drogue leg is far faster); against the requirement's own 150 s window it is
3.08 MB, still 3.9× short. The conclusion does not depend on which window is used.

**The IMU line is 78% of the rate and it is the one that cannot be cut.** Logging raw gyro
and accel at the *propagation* rate rather than the loop rate is what turns GV-2 into a
measurement of `Cm_delta` and `Cl_delta` — and `docs/01` calls GV-2 the flight the whole
thesis rests on. Drop that channel to the 71 Hz loop rate and everything fits on-chip, and
the flight that justifies the vehicle stops producing the data it exists to produce.

So: **W25Q128JVSIQ, 16 MiB, soldered.** 3.4 flights of capacity. Soldered rather than a
microSD socket because every COTS altimeter this project already trusts — StratoLogger,
Raven, TeleMetrum — uses soldered flash, and a push-push socket is an ejection-shock
liability for the sake of convenience that a USB dump also provides. The F405 has no QUADSPI,
so it is plain SPI either way; the SDIO pins stay free if a microSD is ever wanted.

## The board, and where it sits

70 × 45 mm, 1.6 mm PCB, ≤ 8 mm tallest component. Against the sled — which is the arbiter,
not this document:

| | |
|---|---|
| sled plate | 109.04 × 59.41 mm |
| usable height per face | 18.70 mm |
| stack (PCB + tallest part) | 9.6 mm |
| margins | +39.0 mm long, +14.4 mm wide, **+9.1 mm tall** |

**Do not grow this board.** `docs/06` records that the sled already had to widen to 0.846 of
the bore to place the 80 g loom, and past that point width comes out of the tallest
component's headroom. The board is the one line in the nav bay whose size is a design
decision, and shrinking it is the cheapest fix available to the packing problem.

The GNSS patch antenna sets the footprint and can stay on-board: the G12 airframe is
RF-transparent, which is the same reason `correction 32` put the tracker in the nose rather
than worrying about shielding.

**The antenna must be PASSIVE, and the BOM line above used to say "chip or patch" without
saying so.** `U8` pins 13 (`LNA_EN`) and 14 (`VCC_RF`) are no-connects on this board, so
there is nothing to bias an active antenna from — and `RF_IN` has a built-in DC block
(u-blox **UBX-20035208 R08**, Table 13), so feeding one would need an external bias tee at
`J5`, not a jumper. Since most u.FL GNSS antennas sold *are* active, ordering the line as it
was written had a good chance of producing an antenna that silently does not work.

This is a choice the part is built for rather than one it merely tolerates — R08 p.4: *"For
maximum sensitivity in **passive antenna designs**, MAX-M10S integrates an LNA followed by a
SAW filter in the RF path."* If an active antenna is ever wanted for link margin, the change
is an inductor from `VCC_RF` plus a DC block at `J5`, and it is cheapest to make before
layout freezes.

### Bus map

SPI everywhere that is flight-critical. No I2C: a stuck I2C bus is a hung transaction, and
roll angle — which the magnetometer alone observes — is the minimum success criterion.

```
SPI1  (≤24 MHz)  CS1  ICM-42688-P    burst read on DMA, ≥1 kHz  [alone on the bus]
SPI2             CS2  MMC5983MA      magnetometer, 100 Hz
                 CS3  MS5611         barometer, 50 Hz
SPI3             CS4  W25Q128JV      log flash, write-mostly
USART1                MAX-M10S       GNSS, 10 Hz, UBX binary
USART2                debug console  bring-up only
TIM4 CH1-4       PB6 PB7 PB8 PB9     4 × servo PWM, 333 Hz / 1520 µs
SWD              PA13 PA14           flashing and single-step
```

The IMU is alone on SPI1 so its transfer never queues behind a baro conversion or a flash
page program — at 1 kHz with 32× of ODR headroom, jitter is the thing to protect, not
throughput.

## Rejected, and why

| rejected | why |
|---|---|
| **ICM-45686** (±4000 dps, ±32 g) | The range is unusable while the roll cap holds, its rate noise is ~36% worse (3.8 vs 2.8 mdps/√Hz), and its driver ecosystem is far younger. For a first board that last one decides it. |
| **ISM330DHCX / LSM6DSV16X** (±4000 dps) | Same range argument, and ST's gyro sensitivity tolerance is looser than the ICM-42688-P's ±0.5% — scale factor is the dominant error term, so range would be bought with accuracy in exactly the wrong place. |
| **BMI088** | ±2000 dps like the selected part but noisier, with no ecosystem advantage. |
| **Any I2C sensor variant** | Flight-critical sensors on a bus that can hang. |
| **microSD as primary log** | Socket eject under ejection shock, for convenience USB already provides. Footprint left free. |
| **STM32H743** | Already argued in `docs/06`: more rails, finer pitch, harder bring-up. Picking a part you can actually bring up is the engineering judgment. If the F4 flies, an H7 spin afterwards is a week. |
| **Teensy 4.1 as the flight board** | It is Stage 1's part and it stays Stage 1's part — the cert-flight passive logger. `docs/06`'s staging argument is unchanged. |
| **TeleMega** | `docs/06` option B: needs a HAM licence and puts tracking back in the nav bay, undoing correction 32's swappable nose. |
| **Pyro on this board** | Non-negotiable. An independent commercial altimeter fires the charges. A guidance bug must be able to lose the mission without losing the vehicle. |
| **Two cheap IMUs plus a denoising filter** | Redundancy that has not been asked for against a failure mode nothing has characterised, on a vehicle whose dominant error is a scale factor a rate table fixes for free. |

## What it costs

| | USD |
|---|---|
| parts — chips, passives, connectors | 95.50 |
| fab — 4-layer PCB | 30.00 |
| bought whole — StratoLoggerCF + battery | 90.00 |
| spares — IMU + magnetometer | 13.00 |
| **total, hand-assembled** | **228.50** |
| **total, with low-volume PCBA** | **348.50** |

The chips are FPV-class cheap and the pain is process. `docs/04` section 5 carries a flat
**$400** for "custom STM32F405 board"; that is an assembled-board number and it hides roughly
a 3:1 split between silicon and fab. LQFP64 was chosen in `docs/06` partly because it is
hand-solderable, and that choice is what makes the $228 column real.

## Order this, fab this

1. **Read the ICM-45686 scale-factor tolerance** off DS-000577 and record it, so the
   rejection above rests on a datasheet rather than on an assumption. Ten minutes, and it is
   the only unverified number this document leans on.
2. **Order the chips** — MCU, IMU, mag, baro, GNSS, flash, regulator, plus the two spares.
   Order 2–3× of every passive value; shipping costs more than the parts.
3. **Order one StratoLoggerCF and one 2S 1500 mAh pack.** Independent of everything above.
4. **Get the bring-up jig now, not later.** The SPI drivers, the scheduler and the R12 latch
   can all be written and stepped before the PCB exists, and `scripts/sil_demo.py` is already
   the reference for what the loop has to do.
5. **Schematic, then layout.** Four layers. IMU over solid ground, magnetometer as far from
   the servo feed and the battery lead as the outline allows — `estimation.required_magnetic_cleanliness()`
   gives an 18.0 mgauss budget against 40 mgauss from a single untwisted 1 A servo lead at
   50 mm, so twisted pairs and mag placement are power-routing decisions, not aesthetics.
6. **Hold 70 × 45 mm.** If layout wants more, take it out of height, not width.
7. **Fab 5, assemble 1.** The minimum order is five and the spares cost nothing.
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

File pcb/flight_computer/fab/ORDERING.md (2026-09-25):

# Ordering the flight computer at JLCPCB

Generated by `scaffold/fab.py` -- edit the script, not this file.

## PCB (upload `flight_computer-gerbers.zip`)

| option | set to | why |
|---|---|---|
| layers | 4 | |
| thickness | 1.6 mm | |
| **impedance control / stackup** | **JLC04161H-7628** | the netclass widths are solved for its 0.2104 mm prepreg: GNSS_RF 0.36 mm = 50 ohm, USB 0.25/0.15 = 90 ohm diff |
| surface finish | ENIG | two LGA sensors at 0.5 mm pitch want a flat finish |
| outer copper | 1 oz | the 2.0 mm VBATT trunk is sized for 1 oz at 4.1 A |
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

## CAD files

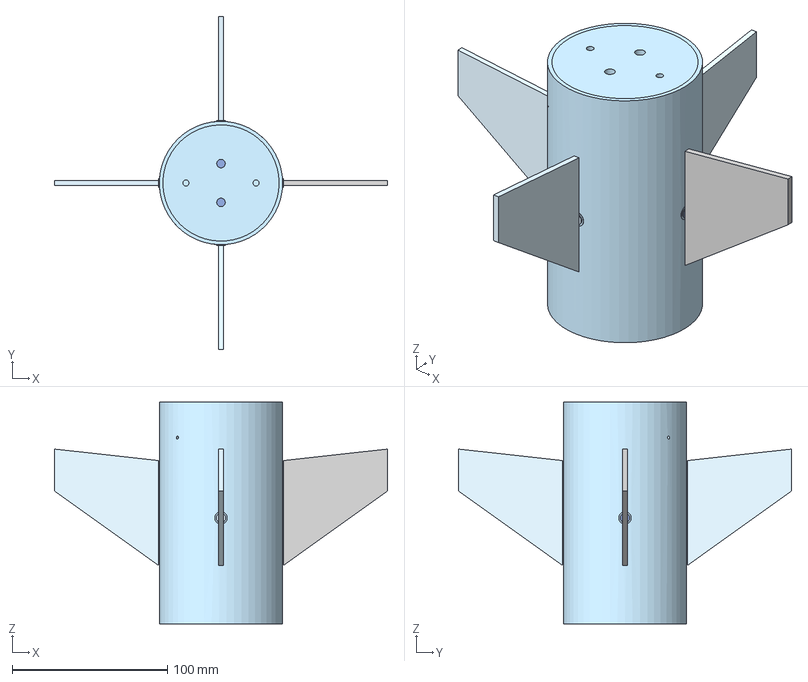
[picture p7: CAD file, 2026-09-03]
cad/onshape_export/Assembly_1.step
214.4 x 214.4 x 142.9 mm
Canard panel 0 (+X)
Canard shaft 0 (+X)
Servo lower boss (keep-out) x 4
Servo output spline (15T, 4 mm) x 4
Servo retainer bar (8 off) x 8
Aft gas seal (G-10, dia 74.8 x 4.8)
Canard panel 1 (+Y)
Canard panel 2 (-X)
Canard bay (printed, PETG-CF)
Servo case + flange (KST X08 Plus) x 4
Hinge bearing (iglidur G, 6/8 x 6 plain) x 4
Canard shaft 2 (-X)
Canard panel 3 (-Y)
Pass-through plate (G-10, dia 74.8 x 2.4)
Canard shaft 1 (+Y)
Canard shaft 3 (-Y)
Canard module tube

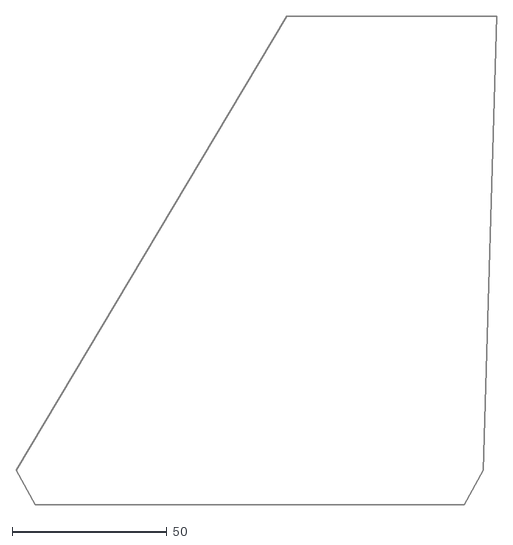
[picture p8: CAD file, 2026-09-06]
out/cad/aft_fin_planform.dxf
155.2 x 158.0

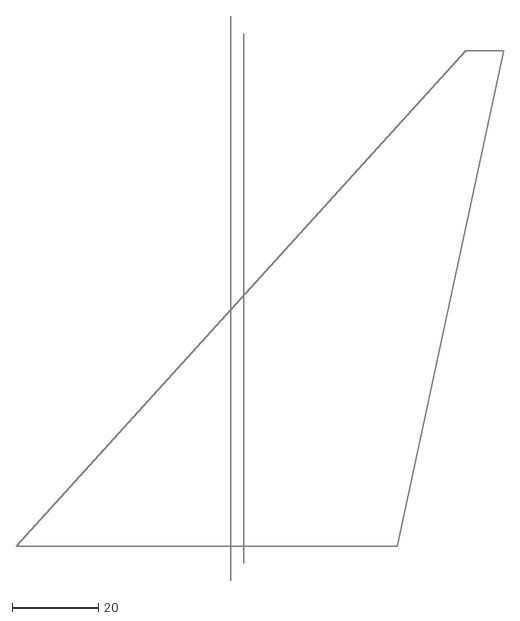
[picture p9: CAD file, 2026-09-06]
out/cad/canard_planform.dxf
113.4 x 131.1

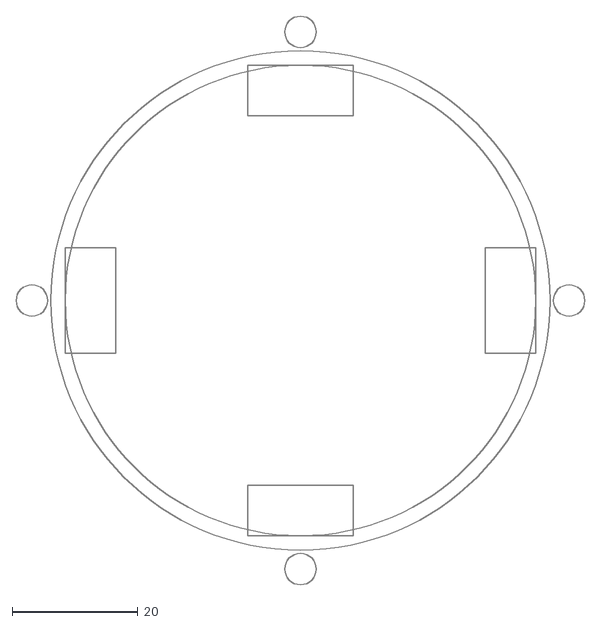
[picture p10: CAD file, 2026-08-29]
out/cad/canard_bay_section.dxf
90.4 x 90.4

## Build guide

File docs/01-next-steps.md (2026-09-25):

# Ordered plan

## State of play — September 2026

Read this first if you are picking the project back up.

- **THE STAGE 2 FLIGHT COMPUTER CAN BE ORDERED NOW, AND SPECIFYING IT FOUND THREE THINGS
  (Sep 2026, correction 64).** `docs/14-flight-computer-bom.md`,
  `design/flight_computer.py`, `python scripts/flight_computer_report.py`, verdict in
  `baseline.py`. STM32F405RGT6 + ICM-42688-P + MMC5983MA + MS5611 + MAX-M10S + W25Q128JV,
  SPI for every flight-critical sensor, UART for the GNSS, 4 × servo PWM on TIM4 at 333 Hz.
  **$228 hand-assembled, $348 with low-volume PCBA** against the flat $400 docs/04 carried —
  the chips are FPV-class cheap and the cost is fab, roughly 3:1. Ejection stays on the
  independent StratoLoggerCF; there is no pyro on this board. **Nothing about the airframe
  moves.** The three findings, none of which was visible from docs/06 or docs/07:
  - **THE ±4000 dps GYRO REQUIREMENT IS DROPPED, NOT BOUGHT.** docs/06 had asked for it, and
    the thing it was checked against was `estimation.GYRO_WIDE` — `measured=False`, no part
    number — which is this project's own rule broken inside the file that states it. The
    option turns out to be **real** (TDK ICM-45686, ±4000 dps and ±32 g, same money), so the
    rejection is now against hardware: the range is **unusable while R13's 2° roll cap
    holds** (566 °/s is 28% of ±2000), correction 58 already showed a wider part flown
    uncapped is ~8× worse, and **the only thing that saturates ±2000 is a fault.** A gyro
    pegged at full scale is DETECTABLE, so it is wired to the R12 latch instead — which
    turns the one scenario the range was for into a detected fault that centres the canards
    inside 0.5 s, for free. `GYRO_WIDE` is deleted and `GYRO_ICM45686` replaces it.
  - **THE SERVO TORQUE MARGIN IS 2.03x ON STALL AND 1.15x ON THE DATASHEET'S OWN CONTINUOUS
    BAND** — two different failure modes, and this project had only ever checked the first.
    The KST X08 Plus datasheet's performance curve carries an operation-model banding
    (continuous only to ~1.2 kgf.cm; the peak hinge moment is 1.04) that no spec table would
    have shown. Nothing fails — the 9.5 s control window is inside the 10 s short-time
    rating — but it is a 1.15x margin read off a chart, and it belongs on Step 5's actuation
    test with a current probe on it. Priced at the HORIZONTAL flight's q, which is R15's
    primary mode; at the sweep's own 25° search elevation it is **2.001x**, on the
    requirement rather than above it.
  - **"ONBOARD FLASH IS ENOUGH" WAS WRONG BY 6x, and the channel that causes it is the one
    GV-2 exists to record.** Written out as a channel list the log is 20.5 kB/s and
    **4.90 MB a flight against 0.79 MB usable on an F405 — 6.2x short**, still 3.9x short
    against the requirement's own 150 s window. Raw IMU at the 1 kHz PROPAGATION rate is
    **78%** of it, and dropping that channel to the 71 Hz loop rate would fit on-chip and
    stop GV-2 measuring `Cm_delta` and `Cl_delta`. So: W25Q128JV, 16 MiB, SOLDERED — every
    COTS altimeter this project trusts uses soldered flash and a microSD socket is an
    ejection-shock liability for convenience USB already provides.
  - Two smaller ones. **There is no BEC** — the KST is rated DC 3.8-8.4 V and the pack is 2S,
    so the servos run direct; 25 g, REPORTED NOT ADOPTED because it changes a checked stack.
    And **capacity was never the battery's constraint**: the flight costs 0.06 Wh of 8.88
    usable, 92% of the demand is an hour armed on the pad, and what actually sizes the pack
    is the **4.1 A peak** with four servos stalled — which is also the number the 14
    conductors through the potted pass-through have never been sized against.

- **THE CANARDS ARE POINTED DELTAS NOW -- 88.6 root / 8.9 tip, 42.2 deg LE (correction 63,
  docs/12 section 13).** A COSMETIC change, asked for as one and priced as one: 9.92 ->
  9.76 deg/s, **-1.63%** against a 3% budget. **A canard outline is NOT free on this
  airframe and two constraints say so.** (1) `hinge.canard_hinge_station` is 0.20c of the
  MAC, so it moves with root/taper/sweep -- change the outline naively and the shaft, four
  collars, four servos and four wall bores move with it. `canard_sweep_cal` is therefore
  SOLVED, not styled: 1.316336 cal holds the hinge to within a NANOMETRE, which is what made
  this a four-panel rebuild instead of a whole-module one. (2) Root chord is then solved so
  SERVO TORQUE IS NOT MADE WORSE -- it stays at exactly 2.067x. Everything else improved:
  bearing 2.11 -> 2.53x, tang 2.02 -> 2.46x, skin 2.49 -> 2.99x, P(SM<1) 0.40 -> 0.34%.
  **THE ONE THING THAT GOT WORSE IS CANARD FLUTTER, 4.50 -> 3.51x** -- flutter takes t/c on
  the ROOT chord and the root chord grew. Still 2.3x the requirement and the aft fins remain
  the critical set at 2.01x, but **a further sharpening spends flutter, not structure.**
  Fusion: Panel0-3 only, interference clean at rest and driven, tensor re-read
  (i_roll -11%), saved.

- **THE VEHICLE TURNS AT 9.76 deg/s ON A HORIZONTAL LAUNCH ON A 893 m RADIUS, AND IT IS
  FROZEN AT 1.45 / 1.85 cal (Sep 2026, corrections 61-63).** P(SM < 1.0) = 0.45%, well
  inside R1. **THE JOURNAL HAS GROWN TWICE TO GET THERE -- dia 6 -> dia 8 -> dia 10 -- and
  the second growth exposed a bug in my own search: `horizontal_agility_sweep` was SIZING
  the hinge without ever calling `check_hinge_stack`, and it picked a 7.0 mm bearing at a
  5.5 mm servo move that leaves 0.59 mm of boss clearance against a 1.0 mm minimum. That is
  the fifth instance of this project's recurring failure and the first one in code written
  to catch it. The sweep now treats `hinge.selected()` as frozen hardware and validates it.
  docs/12 section 11.** Asked for horizontal-launch agility as the primary goal,
  with R1 explicitly not to be defended as a hidden objective, the answer is
  **`docs/12-horizontal-agility.md`** and `scripts/horizontal_agility_sweep.py`
  (output `out/horizontal_agility.txt`). Four things worth knowing before anything else:
  - **Flying flat is worth 1.23x for free.** Gravity stops eating speed (burnout
    141.3 -> 159.8 m/s), the manoeuvre happens in sea-level air, and the frozen vehicle
    goes **6.47 -> 7.95 deg/s** with no part changed. `design/horizontal.py` is a new
    3-DOF that flies the profile; at 85 deg elevation it reproduces `heading_change`
    (6.50 vs 6.47) and `virtual_flight` (6.49), so it is a third integration path and not
    a new model.
  - **docs/11's headline is now scoped.** "Agility comes from static margin, not the
    motor" is TRUE FOR A VERTICAL LAUNCH and is an artefact of R6: the 1600 m apogee cap
    binds before R5's Mach 0.8 can. Flat, apogee is 250-650 m whatever the motor and the
    whole speed band opens. docs/11 carries a pointer at the top now.
  - **R1 IS NOT WHAT IS IN THE WAY ANY MORE, and it was not relaxed.** The recommended
    point sits at P(SM<1.0) = **0.61%** inside R1's 1% budget, at the SAME 1.30/1.70 fins
    and the SAME 60 g of ballast as the vertical freeze. What binds is the **hinge
    bearing** -- peak pressure goes as 1/L^2, a flat flight's max q is 15.5 kPa against
    12.4, and the as-built 6.0 mm bearing falls to **1.57x**. It clears 2.0x at 7.0 mm
    (servo 4.0 -> 5.5 mm inboard) and then RUNS OUT: the four servo cable bosses meet on
    the axis at 6.09 mm of move. That ceiling caps the canard near 1.50 cal, which is why
    the 9.92 deg/s point (1.45/1.85, and BETTER on risk at 0.4%) is blocked.
  - **A flat flight's apogee is not a low-speed event.** 93.8 m/s, not 1.1, because the
    horizontal component never goes away -- so an 18 in drogue there makes 2245 N against
    the 1588 N docs/10 sized the M10 anchors and the harness for. The drogue inverts: it
    is sized by opening shock, not descent rate. **15.4 in** holds the existing design load.
    Nothing else in the recovery chain changes.
  The freeze is: 28 deg rail, deflection cap 8 -> 9.2 deg (a stall limit with 1 deg of
  headroom -- the 8 deg was a ROLL-axis sensing limit, and lifting it for pitch/yaw does
  not touch the gyro), canard laminate 3.6 -> 4.0 mm, hinge bearing 6.0 -> 7.0 mm, drogue
  18 -> 15.4 in, and the HINGE JOURNAL dia 6 -> dia 8 (see below). Vertical mode is the same
  hardware on a 5 deg rail with the SAME 9.2 deg cap -- stall does not know which way the
  rail points -- and it got faster too: **6.47 -> 7.31 deg/s**, apogee 1003 m, SM 2.02-2.41.
  **No ballast swap, no fin swap; the two modes differ by a rail angle and a drogue.**
  Requirements delta APPLIED to docs/00: R2/R6/R11/R12 amended, R13 (deflection), R14
  (hinge bearing + seat), R15 (launch elevation) added.
  - **APPLYING IT COST THREE THINGS THE STUDY DID NOT PREDICT, all downstream of the
    bearing, and docs/12 section 9 is the record.** The proposed 7.0 mm bearing at a 5.5 mm
    servo move FAILED `check_hinge_stack` (0.59 mm of boss clearance against 1.0 mm) -- the
    proposal had flagged it as the tightest margin and it was actually over the line. And
    length was never available: **the bearing cannot exceed 6.2 mm at the as-built servo
    position**, because it grows inboard at the servo's face, and NOTHING CHECKED IT. That
    check exists now. So the JOURNAL grew instead, dia 6 -> dia 8, which is strictly better
    -- no servo move, no central void spent, and the wall over the spline socket goes
    1.00 -> 2.00 mm. Then the chain ran: bearing OD dia 8 -> dia 10, tube net section 13% ->
    17%, bay COLLAR_OD 12 -> 14 mm (1.00 mm of wall failed the 1.60 mm FDM minimum), and a
    hardcoded printed bore that had quietly become a boring operation is now derived.
  - **THE PRINTED BAY'S HOUSING COLLAR IS STRUCTURE NOW.** Bearing-seat crush at the flat
    flight's load is **1.80x on the bare 2.3 mm wall and 12.10x with the collar bonded in**.
    Vertically the bare wall was 2.23x and `design/bay.py` has always priced the collar as
    optional ("a part that exists in CAD is not yet a part that carries load"). It is not
    optional any more. R14.
  - **THE 1.45/1.85 POINT WAS THEN ADOPTED (correction 62), AND THE NUMBER THAT SOLD IT WAS
    WRONG.** The paragraph below is kept as written; read it, then read the correction.
    Re-running the search AFTER the freeze, the dia 8 journal removes the wall that had
    blocked the 1.45 cal canard (1.92x -> 2.27x on the bearing). Fully legal now, R1 and
    all: **1.45/1.85 at 60 g makes 9.92 deg/s at P(SM<1) = 0.45%** -- better than the
    frozen point on BOTH axes -- **1.45/2.00 at 25 g makes 9.93 deg/s at 0.12%**, and a
    **J525 at 1.45/2.00 crosses 10.08 deg/s** on a 327 mm case that still fits the built
    mount. Cost is parts: new canards, new aft fins, and for the last one a new motor. The
    recovery-anchor self-loading chain is the one thing the search still does not run --
    checked by hand, it is 1.04x on an M10 sized at 3.89x, so it converges without changing
    a part. docs/12 section 10.
    **CORRECTION: that 2.27x was measured on a hinge that cannot be built (above). On the
    hinge as frozen, 1.45/1.85 runs at 1.69x and FAILS.** Adopting it properly cost one
    more link: journal dia 8 -> dia 10, bearing OD dia 12, wall bore dia 12 H7 (20% of the
    net section at the hinge station, still passing), bay COLLAR_OD 14 -> 16 mm. **The
    self-loading recovery-anchor chain, which is the one docs/11 records as missed at the
    1.30/1.70 freeze, was run FIRST this time and converged in zero passes** -- dry 6.080 ->
    6.185 kg, opening shock 1604 -> 1660 N, M10 goes 3.69x -> 3.57x on the crown, no size
    change, no mass change, packing still +2.2 mm.
    **TWO MARGINS ARE NOW EFFECTIVELY ON THE LINE: the canard root tang at 2.02x and servo
    torque at 2.07x.** Neither has anywhere to go -- the tang carries panel force and does
    not improve with a thicker laminate, and the KST X08 Plus is the strongest servo that
    fits four-abreast in a 79.4 mm tube. **1.45 cal is the last canard this airframe can
    actuate.** The J525 / 10.08 deg/s motor row was NOT taken.
  - **FUSION IS REBUILT TO THE FINAL FREEZE AND SAVED (correction 62, docs/12 section 12).**
    Rebuilt ONCE, at 1.45/1.85, not at 1.30/1.70 first. Deleted and regenerated Tube,
    Panel0-3, Shaft0-3, CanardBay, Bearing and AftFin0-3 -- 15 occurrences, 24 bodies.
    Servo, nose, nav bay, recovery and motor mount untouched (the servo inboard move never
    changed). **Interference: 14 pairs, every one at exactly 0.000000000 mm3** -- servo in
    its tray, spline in its socket, nose plate in its bore, all coincident faces and no
    volume. Driven check: **144 pairs across 0 / +/-4.6 / +/-9.2 deg, none over 0.05 mm3.**
    `CANARD_MODULE_CAD` re-read and `check_measured_geometry()` is QUIET.
    - **THE DENSITY TRAP FIRED AGAIN, EXACTLY AS control.py PREDICTED IT WOULD.** The
      module came back at 1.574165 kg, 4.08x the true 0.386057, because every rebuilt body
      was Fusion's default Steel. The five custom materials were still in the document so
      this was reassignment, not re-creation. Cross-checked against the repo's own volumes
      x densities: 0.386054 vs Fusion's 0.386057, three parts in a million.
    - **i_roll moved 1313.230 -> 1735.964e-6 kg m^2, +32%**, which is the number that
      matters -- roll inertia sets the bandwidth every gain is scheduled against.
    - Two code defects the rebuild surfaced, both now fixed: the tube's wall-bore volume
      was modelled as pi*r^2*t with a "measured" 0.2 mm3/hole tolerance that was really
      that model's own error at dia 8 and became 0.796 mm3 at dia 12 (there is an exact
      integral now, and the tolerance TIGHTENED 4x); and both joint scripts drove 8.0 deg
      while their docstring claimed it matched DEFLECTION_LIMIT_DEG, so the driven
      interference check was sweeping 87% of the commanded throw. Both derive now.

- **THE 6-DOF SIMULATOR EXISTS, AND BUILDING IT FOUND A 2.26x ERROR IN ROLL DAMPING
  (Sep 2026, correction 60).** `sim/` is a RocketPy-based 6-DOF model built from
  `configure.evaluate()` at runtime; ballistic apogee agrees with `trajectory.py`'s RK4 to
  **0.11%** and max q exactly. Its frame/sign probe (`sim/probe.py`) then found that
  `roll_damping_cl_p()` was **2.26x low** — and settling that took a kinematic-limit argument
  against a third implementation, because **all three codes are wrong in different ways**
  (this repo 2.26x low; OpenRocket damps 2x too hard; RocketPy carries a spurious `Af/A_ref`
  factor). Corrected, all three converge on **Cl_p ≈ 125–150 /rad**. The fix is in
  `aero.single_fin_cn_alpha()` and `FinSet.mean_square_radius`. **The observable barely
  moved** — steady roll 558 → **494 deg/s** at the cap — because `Cl_delta` was low by the
  same shared factor and it cancels in the ratio. **One conclusion did move: the deflection
  limit no longer saturates a ±2000 dps gyro** (1977 deg/s, 99% of full scale), which is
  corrections 55 and 58's premise. The cap survives on no-margin grounds, not saturation.
  Spin-up `tau` halves to **24.8 ms**. Apogee, static margin, crossrange and the 16.8%/73.9%
  interference cancellation are all unchanged.

- **STEP 3'S CAD IS BUILT — the whole vehicle is now real geometry, and building it found
  six defects (Sep 2026, correction 56).** The three queued generators were finally RUN.
  Booster tube + four aft fins at the derived **11.15 mm** tab, the **motor mount** (forward
  bulkhead, mount tube, two centering rings, motor envelope) and the **recovery hardware**
  (4 U-bolts, 4 backing plates, 2 charge wells) are all built and verified against their
  analytic volumes, most at **delta +0.0000**. Interference **12 pairs → 5**.
  **One geometric fact caused three of the six: the fin tab is a TRAPEZOID, not a
  rectangle** — `fin_profile()` ramps it from the root LE to full depth over 6 mm, and both
  the forward centering ring and the tube's own slots were placed as if it began at the
  6 mm station. Fixed by naming the two datums apart (`fin_tab_forward` for the bond,
  `fin_tab_material_forward` for clearance, `SLOT_INSET_MM = 0.0`). Also fixed: the internal
  bulkhead had **one** U-bolt hole pair where correction 54's own comment called for two at
  90°; both bulkheads still carried **⌀5.5** holes after correction 54 took them to ⌀8.5;
  `make_sled_fusion.py`'s bore check had excluded airframe bodies by name and never learned
  about correction 42's `aft coupler`, so it failed a bonded part for not fitting through a
  bore; and a **duplicate orphan fin** (`DiagFin`, 100% coincident with `AftFin0`) was
  deleted. **No vehicle number moves** — feasible, apogee 1270.8 m, dry 5.886 kg.
  **Both real defects are now closed (correction 57) and the CAD is interference-free**:
  the ballast rod has a tapped hole, and the booster anchor's fastener stack is derived per
  anchor -- no washer, low-profile all-metal nut -- fitting the motor's 11.08 mm gap with
  0.58 mm spare, with the check that compares them finally existing. The two superseded
  context bodies are gone and `NoseAftFace` is placed. **Interference is 1 pair at
  1.1936 mm3, which is 1.6 microns of radial overlap** where the nose plate seats into the
  shoulder bore -- two parts that are meant to touch.
- **THE CONTROL ARCHITECTURE WAS RE-OPENED AND SURVIVED — AND ONE SENSOR LINE ITEM NOW HAS
  A DEADLINE (Sep 2026, correction 55).** Asked whether the vehicle could fly sharp,
  precomputed direction changes instead of one slow biased curve, three alternative
  architectures were evaluated and **all three lost to the bank-to-turn design already
  built**: canted fins + spin-and-pulse (its spin rate is a *decaying schedule* that sweeps
  the **4.1 Hz pitch mode**, and a direction change costs half a revolution — 0.25 s early
  but **1.64 s** late), a freewheeling tail (removes **86%** of the vehicle's roll damping,
  and is a passive substitute for an active roll loop this vehicle already has), and
  cold-gas/jet vanes (blocked outright — hardware in a certified motor's exhaust).
  **`ROLL_COMMAND_CAP_DEG = 2.0` costs a factor of four in roll rate, and correction 55
  concluded a wider gyro should buy it back. CORRECTION 58 REVERSED THAT** — running
  `attitude_error_budget()` gives **7.94° capped against 62.89° uncapped**, because the roll
  rate that saturates the gyro is the same one that drives the dominant error term (scale
  factor at roll rate). L1 is *hold roll angle*, so uncapping breaks the thing it was meant
  to enable. At layout: specify **selectable** FS to ±4000 dps and **run at ±2000** — the
  option is free, the capability is not. The real lever is scale-factor **calibration**
  (0.5% spec limit vs ~0.05–0.1% measured). Correction 55's original gap here — that
  `attitude_error_budget()` had **no magnetometer term at all**, so the aided number that
  decides whether the cap can ever move did not exist — **is CLOSED by correction 59**:
  aided, the same 7.94°/31.45° unaided pair becomes **0.08°/0.12°**, and what now actually
  limits roll angle is the airframe's own magnetic cleanliness (an 18.0 mgauss budget
  against one servo lead's 40), not the sensor or the gyro range. Also corrected on the way past:
  the vehicle does not respond sluggishly (pitch quarter-period is **60–68 ms** across every
  geometry tried) — "slow curve" is a lateral-g magnitude problem, not a bandwidth one, so
  the authority/altitude menu in correction 55 is the knob, and **it is left open, not
  taken: `configure.py` still carries 0.85/1.55.** Every number in that correction is from a
  throwaway probe rather than a checked-in script, and all of it sits downstream of the
  unmeasured `Cl_delta`.
- **STEP 3'S DIMENSIONED DRAWING IS CLOSED (Sep 2026, corrections 53 and 54).** The two
  genuinely unsized items — the motor mount, and the recovery bay's U-bolt / backing plate /
  charge well — are both sized, checked, in `baseline.py`, and drawn.
  `design/motor_mount.py` + `docs/09-motor-mount.md`; `design/recovery_hardware.py` +
  `docs/10-recovery-hardware.md`. **Nothing in this vehicle is an allowance any more.**
  Between them they turned up four things worth knowing before anything else is built:
  - **The frozen 12 mm aft-fin tab and a 54 mm motor mount tube cannot both exist.** The tab
    is measured from the booster's OUTER radius, so its tip sat at R 27.70 — 0.85 mm inside
    any mount tube a 54 mm motor can have, and 0.70 mm off the bare motor case, which is what
    the round number was really drawn against. It is **11.15 mm** and derived now. **The four
    `AftFin` bodies and the four booster tab slots must be rebuilt in Fusion.**
  - **The Pro54's own forward-closure ejection charge fires into a sealed 25.9 cm³** between
    the motor and the booster's forward bulkhead — 10.2 MPa against a disc that lets go at
    6.69, and it fails at every plausible charge mass. **Buy the plugged forward closure.**
    Nothing in this project had ever asked what happens to the motor's own charge.
  - **The M5 U-bolt `seal.py` assumed does not carry its own load.** Its aside checked the
    LEGS in SHEAR; the legs are in tension and the CROWN is what bends. **M8**, and the
    ⌀5.5 holes already placed in both bulkheads become ⌀8.5.
  - **The 3/4" harness does not pass through the U-bolt** (19.1 mm of webbing, 17.0 mm of
    opening). It was never meant to: the harness attaches through a **quick link**, which
    `recovery.py` has priced since it was written.
  Vehicle level, from 191 g of harness anchors `mass.py` had no line for at all: dry
  **5.68 → 5.89 kg**, apogee **1326 → 1271 m**, crossrange **340 → 297 m**, static margin
  **2.30–2.77 cal**, recovery bay margin **+8.35 → +4.63 mm**. No requirement moves out of
  bounds. **What is left is CAD execution, not design:** the two Fusion generators are
  written and their emitted scripts verified offline, and running them in Fusion — with the
  fin rebuild first — is the remaining step.
- **CAD moved from Onshape to Fusion, and full-module migration is DONE (Sep 2026).**
  Everything below this bullet through the end of "State of play" predates that move and
  is Onshape-only history — read it for the ENGINEERING content (the hinge, the joints,
  the loads all still apply), not for which CAD tool to open. `CanardControlModule` in
  Fusion now holds the tube, 4 panels, 4 shafts, the printed bay, 4 servos, 4 bearings,
  the aft gas seal and the pass-through plate as native, from-scratch, regeneratable
  geometry (eight generator scripts under `scripts/*_fusion.py`, each deriving every
  dimension from `design/*.py`, same discipline as the Onshape scripts below), all
  correctly placed, interference-clean at rest AND driven through 0°/±4°/±8° deflection,
  genuinely ARTICULATING on 8 native `AsBuiltJoint`s — and **`Onshape_reference` (the STEP
  import) and the old hand-built 28-body rebuild are both DELETED from the live document.**
  Full blow-by-blow in **corrections 44–50** at the bottom of this file (M0 plumbing/
  joint-API spike, M1 bay, M2 servo+bearing, M3 tube/panel/shaft, M4 placement+
  interference, M5 joints, M6 cutover) — read correction 44 first for the architecture and
  milestone list, then whichever of 45–50 you need. Onshape's `canard-control module`
  document is untouched and still the thing the *rest* of this file's Onshape-era
  corrections describe — it is history now, not a live dependency of anything that moves.
- **The recovery bay has a tube now, and its internal bulkhead is finally assembled, not
  just drawn (Sep 2026, correction 51).** `scripts/make_recovery_bay_cad_fusion.py` builds
  `RecoveryBayTube` (357.3 mm, the same OD/ID as the canard module's own tube) directly
  aft of the canard module in the same `CanardControlModule` document — Z 142.92 → 500.22,
  continuing from the aft gas seal's own aft face — and moves the already-built
  `RecoveryInternalBulkhead` (correction 50) from its unplaced local origin to its real
  station, read off `evaluate().packing`'s own main/drogue compartment lengths rather than
  assumed: main compartment forward (229.50 mm), the bulkhead centred in its 10.8 mm
  allowance band, drogue compartment aft (89.72 mm), 27.3 mm of slack left at the tube's
  own aft face for the recovery-bay/booster joint's coupler. Interference-clean against the
  tube, the aft gas seal, and the canard module's own tube. **Still open, and not drawable
  yet**: the U-bolt, backing plate and charge well — none of the three has ever been SIZED
  by anything in this project, Onshape included, so drawing them now would be inventing a
  design decision rather than recording one.
- **The booster tube and all four aft fins are drawn (Sep 2026, correction 52) — the
  vehicle is modelled nose to tail in Fusion for the first time.** Correction 51 assumed
  the booster + aft fins had no design-side sizing at all; checking before drawing found
  that was wrong — the planform (`aft_root_cal`/`aft_semispan_cal`/`aft_sweep_cal`/
  `aft_taper`, `design/configure.py`) and the root attachment (a 12 mm through-wall tab,
  already baked into `scripts/make_cad_profiles.py`'s `fin_profile()`) were both already
  decided, just never built as 3D geometry. `scripts/make_aft_fin_cad_fusion.py` builds
  `BoosterTube` (continuing directly from `RecoveryBayTube`'s own aft face) and
  `AftFin0`-`AftFin3`, clocked 45/135/225/315° (interdigitated 45° off the canards, a
  number this project had only ever stated in prose until now). Interference-clean
  everywhere: tube-to-tube, fin-to-tube, and every fin pair, all exactly 0.0000 mm³. Found
  and fixed a real Fusion API gotcha along the way — renaming a Sketch/Extrude-sourced body
  inside the same script transaction does not reliably persist, even into a fresh empty
  component; `scripts/fusion_common.py`'s shared `_inject()` now renames after
  `finishEdit()` via a fresh query instead. **Only the motor mount (never sized by
  anything, Onshape included) and the recovery bay's U-bolt/backing-plate/charge-well
  (correction 51) are what's left of Step 3's dimensioned-drawing deliverable.**
- **Steps 0, 1, 2 are closed.** Sizing tool built, range access and certification path
  resolved, OpenRocket cross-check done and agreeing (CNa to 0.3%, CP to 0.17 cal).
- **Step 3 is closed** (corrections 53 and 54; see the top bullet). The airframe is frozen
  in `design/configure.py` — that file
  is the single source of truth for the vehicle and every script imports from it. The BOM
  is drafted (`04-bill-of-materials.md`). **The dimensioned drawing now covers the whole
  vehicle except the motor mount and the recovery bay's U-bolt/backing-plate/charge-well**
  (both genuinely unsized, not just undrawn) — CAD work in Fusion (`CanardControlModule`),
  see the two bullets above; do not go looking for any of it in Onshape.
- **The canard module inertia is measured**, not estimated. `design/control.py` now
  superposes the CAD tensor (`CANARD_MODULE_CAD`) on the crude bulk estimate: vehicle roll
  inertia up 6.4%, pitch down 1.5%, pitch mode 4.30 → 4.34 Hz, roll acceleration down ~6%.
  Roll is the axis GV-3 flies, so the 6.4% is the one that matters. The tensor is now read
  off `Assembly 1` rather than Part Studio 1, because the servos are real parts in their own
  studio and only share a frame once assembled. The rest of the airframe is still ±30% until
  you swing it.
- **The CAD is now driven through the Onshape REST API, not the browser.** That change paid
  for itself immediately: reading the feature tree as JSON exposed two defects that clicking
  around had hidden for weeks — a hinge dimension measured to a circle's tangent instead of
  its centre, and a `Hinge Plane` datum that drove no geometry at all. Between them the
  physical hinge sat at 0.029 of MAC instead of 0.200, which is a **0.82× servo torque
  margin against a 2.0× requirement**. Both are fixed and verified; see `docs/05`.
  **If you touch the CAD again, use the API.** Credentials live outside the repo.
- **The servos in the CAD are now the real part, and the CAD articulates.** The
  23.5 × 8 × 16.8 envelope block is superseded by KST X08 Plus geometry built from the
  datasheet, in its own Part Studio, and `Assembly 1` holds the module and four servos in
  position. `python scripts/canard_sweep.py` drives the canards through ±8° for real and
  reports clearances — the interference check `docs/05` had carried as NOT RUN since the
  module was built. Two things the block had hidden came out of it; they are corrections 9
  and 10 below. The four revolute hinge mates are the one piece not finished: the mate
  connectors and the rigid groups are in — **and as of Aug 2026 so are the mates**, added in
  the browser because the API will not author that connector reference. `Assembly 1` now
  carries `Canard 0 (+X) hinge` … `Canard 3 (-Y) hinge`, REVOLUTE, each pairing
  `tube{n}` with `shaft{n}`. Mass and CoM did not move, which is how you know the paired
  connectors really were coincident. **They did not actually turn until Sep 2026** — the
  ±8° mate limit froze all four, and no one had ever driven one to find out
  (correction 39). Limits are off now, the deflection limit lives where it is enforced
  (`DEFLECTION_LIMIT_DEG`), and `scripts/fix_hinge_mate_limits.py --verify` drives every
  hinge and parks it at zero.
- **The hinge is a mechanism now, and closing it found a third thing.** Both fits
  correction 10 left open are closed — see correction 11 and `docs/05` "The hinge stack".
  `design/hinge.py` models the shaft, bearing and coupling as a load path rather than as a
  set of dimensions; `scripts/hinge_report.py` prints it; `scripts/make_hinge_stack.py`
  applies it to Onshape and is safe to re-run. `scripts/baseline.py` now carries a
  hinge-stack verdict, and the check is run against the **as-built** layout too, where it
  fails on five counts. A check that has never failed is not evidence of anything.
- **The hinge load path is closed end to end.** The two items the hinge stack left open
  are both done (corrections 12–14): the **sleeve-to-panel joint** is a 1.8 × 11.9 mm
  tang 25.5 mm into the root — which turns the panel into a 0.6/2.0/0.6 bonded laminate,
  a manufacturing change and not a design one — and the **tube at the hinge station** is
  checked and passes by two to three orders of magnitude on everything except the bearing
  seat, which sits at 3.2× *only* because the housing collar has not been built.
  `design/tube_section.py` and `design/materials.py` are new; `design/hinge.py` carries the
  joint; `scripts/hinge_report.py` prints both and `scripts/baseline.py` carries both
  verdicts so neither can silently regress. **The one open item in the whole hinge is the
  housing collar** — no longer blocked (correction 16 removed the bracket it was waiting
  on), and worth a measured **3.4× → 14.5×** on the bearing seat — see correction 19,
  which is where the 21.3× this document used to quote went.
- **The bearing is geometry now, not a dimension.** It was the last part of the hinge that
  existed only as a number, and an unmodelled part cannot collide with anything — the same
  trap that hid a hard servo clash for weeks when the servo was a bounding box. Part Studio
  `Hinge bearing (⌀6/8 × 6 plain)` holds it, and all four are instanced in `Assembly 1` on
  their hinge axes at R 39.700, in the airframe rigid group because a pressed race does not
  rotate with the panel. `scripts/make_bearing_cad.py` builds it, `scripts/place_bearings.py`
  places it, both are safe to re-run. **This is what the printed bay's collar now gets drawn
  against.**

- **The printed bay is built** (correction 19). `design/bay.py` models it, `cad/canard_bay.fs`
  and `scripts/make_bay_cad.py` build it, `scripts/bay_report.py` prints the argument, and
  `Assembly 1` holds it at identity along with eight retainer bars. One PETG-CF print, 39 g.
  **The hinge load path is now geometry end to end**, tube to panel, with nothing left as a
  dimension. Two things it turned up are open and neither is a bay problem: **the coupling**
  (no bought servo horn fits in 0.515 mm — correction 19) and **the aft gas seal**, which is
  a bulkhead and has never been sized.
- **The coupling is closed** (correction 21). The shaft's inboard end takes a plain
  ⌀4.100 × 3.20 drilled socket, bonded onto the servo spline with anaerobic retaining
  compound that cures into the tooth valleys and becomes the female spline. No broaching, no
  bought adapter, and it comes apart with heat. Cut in the CAD.
- **The aft gas seal is sized, and it was never a seal** (correction 25). `design/seal.py`,
  `scripts/seal_report.py`, verdict in `scripts/baseline.py`, write-up in `docs/05`. A
  **G-10 disc, 4.8 mm, 39 g** — sized not against gas tightness but against being the piston
  the ejection charge pushes on (7329 N in the stuck-joint case) and the anchor the main
  pulls on (1338 N).
- **Everything the seal opened is now closed too**, and each one turned out to be a
  different kind of problem:
  - **The internal bulkhead**, which was a 12.0 mm length allowance in `recovery.py` and
    nothing else, is now the same model applied a second time — **4.8 mm, 39 g**, with a
    charge on both faces and, unlike the seal, **no shear pins protecting it**. Both come
    out at the same pressure for a reason worth knowing: correction 29.
  - **The drogue's firing circuit** runs in a ⌀5 mm bonded conduit through the main
    compartment. Priced in `recovery.py` along with the four U-bolts nobody had counted, and
    together they take the recovery bay's margin from **+13.0 mm to +6.8 mm**. Still fits.
  - **The venting** is `design/venting.py`, and it corrects the seal's own argument
    (correction 28). The canard module vents through **its own wall**, so it is not in the
    altimeter's sense volume and the wiring pass-through is potted solid.
  - **The nav bay has a packing check now** (`design/avionics.py`,
    `scripts/avionics_report.py`) and **it still does not pass**. The tracker and the
    telemetry radio moved into the nose (correction 30) and the shoulder question is settled
    (correction 31); between them the gap went 47 mm → **9 mm short** on estimated
    envelopes. Read correction 27 before doing anything more — this is correction 5's exact
    trap, and it is an `evaluate()` **warning**, not a violation.
- **The joints are modelled** (correction 31). `design/joints.py` — all four of them, which
  `tube_section.py` has wanted since it was written. **A coupler is a tube and its bore is
  usable**, so it costs local diameter and not bay length; only bulkheads cost length. That
  settled the nose shoulder, and it also took the recovery bay from +6.8 mm to +0.1 mm.
- **The recovery bay margin is fixed, and the harness is why** (correction 33). It went to
  **+17.8 mm**, and is **+8.4 mm** now that correction 42 made the joints pay for both of
  their halves. The fix was not to shave anything: **nothing in this project had
  ever sized the harness.** Its volume came from a budget line nobody had checked, divided
  by an assumed bulk density; its strength came from nowhere. Sized against the opening
  shock it actually carries, it is **3/4" tubular nylon at 4.2×** rather than 1" at 6.7×.
- **The nose is the instrumentation module, and it is meant to come off** (correction 32).
  Tracker and telemetry radio live there, self-contained, on one connector. A future payload
  of **up to about 300 g needs no other change**; past that the vehicle goes over-stable
  rather than unstable, and the nose ballast is the trim knob.
- **Both bulkheads are CAD now** (correction 34). `scripts/make_bulkhead_cad.py` builds
  them, `scripts/place_bulkhead.py` puts the aft gas seal in `Assembly 1` at Z = 142.900,
  and Onshape's own **Check interference reports none across all 35 instances**. Volumes
  agree with the analytic disc-less-holes to 0.000 mm³. **Read the caveat in correction 34
  before trusting that clean result.**
- **The two module vents are CUT** (correction 37). 2 × ⌀2.0 mm at **Z 120.0 mm**, clocked
  **45° / 225°**, placed in `design/venting.py` and cut by `scripts/make_module_vents.py`.
  The station is chosen by the **leak path**, not the flow field — see `docs/05`.
- **The canard module has one open engineering item after all, and it is not in the
  module** (correction 37). The forward wiring pass-through cannot be drawn because **the
  plate it passes through has never been sized**: `joints.py` puts a bulkhead on all four
  joints, `seal.py` sizes the two separation ones, and **neither access bulkhead — the
  nav bay / canard module plate, and the nose's aft face — has ever been sized by
  anything**, while both already spend bay length as allowances. What is otherwise left is
  the Step 3 drawing.
- **Both access bulkheads are sized, and neither is sized by stress** (correction 38).
  `design/access_bulkhead.py`, `scripts/access_bulkhead_report.py`, verdict in
  `baseline.py`. Both clear the thinnest stocked G-10 sheet by 25×+ on every load found —
  the pass-through plate because the bays either side of it (nav bay, canard module) both
  vent to ambient **on their own**, so the only load across it is the nav-bay/module venting
  **lag differential**, about 5.5 Pa; the nose plate against the **trapped
  pad-to-apogee differential** (15.4 kPa, conservative — see below) plus a **300 g payload
  point load** at max boost accel, correction 32's provision ceiling rather than the 105 g
  actually flying. **What actually sets both plates is producibility** — holding a screw
  thread through repeated disassembly, a connector's panel-nut torque — which has no stress
  model here, so a stated practical floor stands in: **2.4 mm / 19.5 g** for the pass-through
  plate, **3.2 mm / 26.0 g** for the nose plate. Same shape of result as `venting.py`'s port
  sizing: the model gives the floor, practice gives the design point.
  `CANARD_MODULE_FREE_VOLUME` also stopped being a two-script duplicate and now lives in
  `design/venting.py`, since this was its third caller.
  **One real gap surfaced, not closed: the nose cavity's own venting has never been modelled
  anywhere in this project** — `design/avionics.py` and `design/venting.py` both stop at the
  nav bay. The nose plate is checked against the fully-sealed case until that gap is closed;
  if a nose vent is added later, that load goes away and the plate stays oversized rather
  than becomes undersized. Two part numbers are still open and don't move the plate: the
  pass-through's wire bundle (no gauge has ever been chosen) and the nose module's panel
  connector. **The pass-through can now be drawn.**
  Both plates are CAD now too: `scripts/make_access_bulkhead_cad.py` builds them (volume
  verified against the analytic disc-less-hole figure on the first build), and
  `scripts/place_access_bulkhead.py` instances the pass-through plate in `Assembly 1` at
  Z = 0.000 — the module's forward face, with identity transform because the disc's own
  frame is built as the aft seal's *mirror* (origin on the forward face, growing aft) rather
  than a copy of it. **Check interference reports none across all 36 instances.** The nose
  plate is a part only, same reasoning as the internal bulkhead: its cavity is unmodelled.
- **D7 is CLOSED** (correction 35). A **custom STM32F405 board** flies the guided vehicle
  and a **Teensy + breakout stack** flies the L1/L2 certs as a passive logger — staged in
  that order, because the cert launches are monthly and eight weeks of PCB work would spend
  them. Deployment stays on an independent commercial altimeter in both stages.
  `docs/06-avionics-selection.md`, `scripts/avionics_trade.py`. **And it dissolved the nav
  bay warning**: every architecture fits, because the guessed flight computer was 2.5× the
  size of the real part.
- **D8 is CLOSED** (correction 36). **IMU + baro + GNSS + magnetometer**, with the
  **estimator staged by guidance level** rather than the sensor set — D7 could stage the
  hardware because a PCB takes eight weeks; D8 cannot, because every sensor has to be on the
  schematic at once. `docs/07-state-estimation.md`, `design/estimation.py`,
  `scripts/estimation_trade.py`, and a verdict in `baseline.py`. It closes **without D1**.
  Four findings, and all four are free before layout and unrecoverable after: **the |a| gate
  this document prescribed opens at burnout and admits drag as gravity**; **the IMU must
  sample at 1 kHz, which is not the 86 Hz control loop rate**; **roll angle was observed by
  nothing on D7's board**, and L1 is defined on roll angle; and **D7's gyro figure was
  computed at 6° and printed under an 8° heading** — the real number at the deflection limit
  saturates a ±2000 dps part. **Step 4.2 below is corrected; do not build from the old
  version.**
- **Correction 37 is the CAD one**, and it came out of finally trying to draw the last two
  holes in the canard module. The vents are cut. The pass-through is not, and the reason is
  the finding: **two of the vehicle's four joint bulkheads have never been sized by any
  model**, and they were invisible because `joints.budgets()` already charges bay length
  for them and `seal.py`'s exclusion list named only the booster's. An allowance that
  nobody turned into a part, for the third time in this project.
- **The Fusion 360 rebuild does not match the Onshape module, and the servos were not why**
  (correction 40). `cad/onshape_export/Assembly_1.step` is imported into the Fusion file
  next to the native rebuild, so the two can be booleaned body-for-body. Four parts
  transferred exactly and the **servos are provably correct** — the merged servo body is
  13.3518 mm3 heavy, which to four decimals is the six flange holes that were not cut, and
  every dimension in `SERVO_GEOMETRY` survived. Two findings are load path and make the
  module unbuildable: **all six radial holes in the tube are blind**, stopping on a plane
  tangent to the bore and leaving a 0.2145 mm crescent web that the bearings and shafts run
  into (and the two vents therefore do not vent, undoing correction 37); and **the bay's
  four bearing bores are plugged by 2.400 mm of uncut shell wall**, with the collar bosses
  run out to R 37.400 instead of R 36.500 so they bury themselves in the tube. Pairwise
  boolean says it plainly: **21 clashing pairs at 0.85-52.95 mm3 in the rebuild, against 6
  tolerance slivers all under 0.028 mm3 in the reference.** Also open, and pointing the
  other way: the Onshape bearing carries ~0.3 mm lead-in chamfers that
  `scripts/make_bearing_cad.py` does not know about. **All four are fixed and the file is
  saved** -- and the repair re-used the check, because for a rebuild that is a superset of
  its source the reference solid is also the cutting tool: `rebuild - (rebuild - reference)`
  lands it exactly, with no dimension re-typed. Tube and bay now boolean to an **empty**
  difference against Onshape; interference is **4 pairs at 0.0192 mm3 against the
  reference's own 6 at 0.0278**, which is parity and is the right bar -- a STEP round trip
  will not reproduce coincident faces to zero. The extra tray webs were confirmed
  unintentional and cut (1127 mm3, ~1.5 g). Still open by choice: the bearing chamfer,
  which belongs in Onshape or in the script rather than in the rebuild. Full write-up in
  `docs/05`, "The Fusion 360 transfer". **Volume and mass agreement is not model
  agreement** -- none of this moved a gram.
- **The nav bay sled is a part now, and drawing it found three things** (correction 41).
  `design/sled.py`, `scripts/sled_report.py`, `scripts/make_sled_fusion.py`, verdict in
  `baseline.py`, full write-up in `docs/08-nav-bay-sled.md`. The sled was the fourth
  allowance in this project to be priced without existing: `mass.py` has charged **150 g**
  for `sled_and_hardware` since that dict was written and `avionics.SLED_WIDTH_FRACTION`
  set its width, for a part nobody had drawn. It is **G-10 plate 109.04 x 59.41 x 1.6 mm,
  two end brackets, two M4 rods, 101.6 g** against that 150 g, in Fusion as `NavBay` at
  Z -127.04 -> -12.00 with the nav bay tube, the nose shoulder and the nose plate drawn
  around it. Three findings, and the first is the one that matters:
  - **0.80 OF THE BORE IS TOO NARROW TO CARRY THE WIRING THE SAME FILE CHARGES FOR.**
    `avionics.check_packing()` is an **areal** model -- footprint summed and divided by
    `2 x sled_width x 0.70` -- and it reports the bay FITS by +4.6 mm. Place the same stack
    as **real rectangles on two faces** (exhaustive over face assignment and 0/90
    orientation, exact within a face, so a negative is a proof and not a search that gave
    up) and the four boards fit fine, but the **80 g wiring loom then has nowhere to go**:
    no 70 x 20 mm rectangle left on either face, and the corner crescents would need it at
    **1.82 g/cm3** against copper's 8.96 and PVC's 1.4. The plate has to reach **59 mm**.
    An areal model cannot see this because it only ever sees the product -- it cannot tell
    a plate 2.84 mm too narrow from one that is wide enough. `configure.py` now passes the
    real sled width into `check_packing()` instead of the 0.80 fallback, and the areal
    margin goes **+4.6 -> +10.7 mm** as a *result* of the part improving, not as a retune.
  - **THE MOUNT AS FIRST DRAWN DID NOT HOLD ANYTHING.** Rods beside the plate, in its own
    plane, is what a side-view sketch gives and it is wrong in three dimensions: a nut on
    an axial rod clamps axially, and a plate in that rod's plane offers nothing but its
    1.6 mm edge for a washer to bear on. Ears around the rods do not help -- the rod runs
    the whole bay, so clearing it removes every scrap of ear at that radius. Pairwise
    interference said it in one line: **47.31 mm3 of plate inside each rod.** The capture
    has to be **perpendicular** to the rod -- an end bracket, a bulkhead in miniature -- and
    once it is, the rods can move off the plate's plane, where they stop competing with its
    width and can come inboard to **R 30.00**, taking the hole ligament from **-0.05 mm to
    2.55 mm** in the bracket and from 2.55 to **5.15 mm** in the two end plates, which
    matters more because those are pressure boundaries. The rods were also **12 mm too
    short** -- drawn the length of the sled instead of the length of the bay, so a "simply
    supported" sled was supported at one end by nothing.
  - **TWO MOUNTING SCREWS COLLIDED AND NOTHING SAW IT UNTIL THE VOLUME DID.** The BEC's and
    the altimeter's corner screws landed exactly on top of each other at one corner and
    1.30 mm apart at another -- two holes 1.30 mm apart are one ragged slot. Found because
    the CAD came back **+10.7519 mm3** against the analytic figure and the two overlaps
    accounted for it to the last hundredth. Colliding holes now merge into shared
    through-holes with a standoff each side.
  **STILL OPEN AND STATED RATHER THAN SOLVED:** the loom result has a second reading --
  the 80 g is a `mass.py` line called `wiring_connectors`, connectors are not loom, and the
  servo and pyro leads both run AFT out of this bay -- so **nothing was resized and
  `avionics.py`'s model was not edited** (correction 5's discipline). Weighing the loom and
  counting its conductors settles it and has never been done. Also open: **battery and loom
  retention is not drawn** -- 1.00 mm of clear plate beside the battery against the ~3 mm a
  cable-tie slot needs, so the two heaviest items on the sled are held by nothing that
  exists yet. Interference is **zero pairs involving any sled body** across 861, and
  **0.0000 mm3 of the sled lies outside the 70.20 mm shoulder bore** -- the "does it slide
  past the nose shoulder" check no script in this repo had ever performed. Three stale
  strings fixed on the way past: `avionics_report.py` hardcoded "STILL SHORT BY 14 mm"
  **directly under its own computed FITS verdict**, `avionics.py`'s docstring worked its
  example at a sled width the model never produces, and `docs/04` section 5 still said
  9 mm short. Next in this bay: the nav bay's static ports still have **no station and no
  clocking** anywhere in the repo.
- **The nav bay's static ports are placed, and placing them found that the nav bay has no
  bare wall** (correction 42). `design/ports.py`, `scripts/port_report.py`, verdict in
  `baseline.py`, and it is built and interference-checked in Fusion. **3 × ⌀3.2 mm at
  station 420.82 mm, clocked 15/135/255°, 4.60 mm deep**, through the airframe tube *and
  the bonded aft coupler together*, because that band is the only drillable wall
  there is: the nose shoulder takes the forward caliber and that joint comes apart. The cause
  is that **`joints.py` described a joint only by the half that PROTRUDES**, so nothing could
  ask whether a bay had room for the anchored half — and **two 1.0 cal joints do not fit in a
  1.60 cal tube.** `anchor` is a field now and `check_joints()` is the check; the nav bay is
  exactly full, and **the canard module failed it by 15.88 mm — resolved same-session,
  correction 42's second half** (below): both of its joints are bounded by the printed
  bay sitting mid-tube, not by convention, and fit with 43.9 mm spare once derived from
  the bay's own footprint. One number moved elsewhere: the recovery bay's packing margin
  **+17.8 → +8.4 mm**, because `bay_budget` was taking the `max` of a bay's two narrowed
  spans instead of their sum. Four findings, and the two worth carrying are that **neither
  conventional placement rule can be met and it costs about a metre** (the error is only
  ever read where q is small), and that **the port-count argument came out backwards from
  the first guess** — four ports is the more accurate ring and three is the forgiving one,
  because a 4-port ring's clocking is load-bearing against a four-canard vehicle's own
  field and a 3-port ring's is not.
- **The hinge mechanism actually articulates in CAD now, and the nose cone is drawn for the
  first time** (correction 43). Neither was true before this session: the canard hinges had
  mates in Onshape (correction 39) but nothing equivalent existed in the Fusion document,
  and the nose cone had never been more than the parametric shape `aero`/`mass`/`avionics`
  read numbers off. Fixed together, in Fusion, and verified rather than assumed:
  - **Four AS-BUILT joints** (one rigid panel-to-shaft bond, one revolute shaft-to-tube
    hinge, per canard) connect the STEP-imported reference assembly's own components — an
    as-built joint freezes the current position and never snaps geometry to align, which
    matters here because nothing but the STEP import's own accuracy holds these parts
    together. Driven to 8° and screenshotted before being trusted, then reset to 0° — the
    same rule this project has applied to every mate since correction 39: a joint that
    "added successfully" and one that actually turns are different claims.
  - **The nose cone is a real part**: the ogive shell (piecewise-frustum revolve, 150
    segments, verified against an independent 20000-step numerical integration to 0.0007%)
    plus its integral shoulder — the same material `design/joints.py`'s nose/nav-bay joint
    already priced from the nav bay's side, now drawn from the nose's own side instead of
    left as an anonymous annular placeholder. Found in the process: **the wetted-area mass
    estimate `design/mass.py` had used since before this project's history began was ~113 g
    light** — it approximates a thin constant-thickness shell reasonably for the ogive
    (~180 g estimate against ~216 g real) but never counted the shoulder at all (~77 g).
    `design/mass.py` now prices the nose cone from the real drawn volume.
  - **The adjustable ballast provision also has real hardware for the first time**:
    `design/nose_module.py` sizes an M6 rod and a 25×6.5 mm steel washer stack to the
    design-point 100 g (docs/00 §7.1) — a mass and a station existed for this since D10
    closed; a rod diameter and a washer size did not. The rod itself is genuinely new mass
    (33.6 g) that nothing had ever charged for, the same shape as the sled's rods, the
    U-bolts, and every other "priced but not drawn" gap this project keeps finding.
  - **The vehicle got heavier and MORE stable, not less**: +156 g total, almost all of it
    forward of the CG, moves static margin **2.11–2.60 → 2.27–2.76 cal** and P(SM<1.0)
    **0.2% → 0.1%** — at the cost of apogee (1369 → 1326 m) and crossrange (400 → 340 m).
    Nothing was retuned to get this; it fell out of the mass model becoming honest. See
    `scripts/baseline.py` and `scripts/robustness.py` for the regenerated figures.
  - A performance regression was caught, not shipped: the first version of the new nose
    mass calculation ran a 4000-step integration inside `evaluate()`, which every optimizer
    in this project calls thousands of times per run. Measured before committing to it —
    `evaluate()` cost ~300 ms regardless of step count, an existing cost this change did not
    create — and the step count was still cut to 200 on the general principle that a hot
    loop should not carry unneeded weight. See `design/nose_module.py`'s
    `shell_volume_and_centroid` docstring for the numbers.
- **Asked whether Step 4 (firmware) was really next, the honest answer was no.** By the end
  of correction 52 the whole vehicle has real CAD, nose to aft fins, in one document. **What
  is left standing between here and Step 3's own deliverable, "a dimensioned drawing"
  covering the whole vehicle, is two genuinely unsized items, not undrawn ones**: the
  recovery bay's U-bolt/backing-plate/charge-well and the booster's motor mount — neither
  has ever been sized by anything in this project, Onshape included, so neither is a CAD
  task until it is a design decision. Step 4 is still next in the sense that
  D8 settled what it is built from, but calling it "next" before Step 3's drawing covers the
  whole vehicle was premature, and correction 43 exists because that got questioned rather
  than assumed.

Current vehicle: 79.4 mm OD fiberglass, 1361 mm, canards 0.85 cal / aft fins 1.55 cal
interdigitated 45°, **both sets swept 35.4°**, Cesaroni J449 Blue Streak, 4× KST X08 Plus
servos flat-mounted with the hinge at 0.20 of MAC, 100 g nose ballast. Canards 67.5 root /
27.0 tip (0.40 taper). **6.30 kg wet, apogee 1326 m, Mach 0.513, static margin
2.27–2.76 cal, P(SM<1.0) 0.1%, 340 m crossrange.** (Mass +156 g and margin up since Sep
2026 correction 43, when the nose cone was finally drawn and its real volume — including
the integral shoulder, never counted before — replaced a wetted-area estimate.) Telemetry
radio and GPS tracker ride in
the **nose** at station 300 mm, not in the nav bay (correction 30). Every one of those
figures moved in Aug 2026 — the missing dual-deploy altimeter (correction 26) and then the
nose move. `scripts/baseline.py` regenerates
all of it; `evaluate()` reports feasible with no violations, and that now includes a check
that the recovery hardware physically fits in the bay.

**One open decision you should know about before the defence:** §7 used to claim the
selected fin sizes gave the highest crossrange of any combination that passes every
constraint. They do not. `scripts/robustness.py` now picks **canard 1.15 / aft 1.85 cal**,
which passes everything and buys **514 m against the selected 390 m** — 32% more. It costs
flutter margin and servo torque; run the script for the current figures rather than quoting
these, because they moved once already when the altimeter went into the budget
(correction 26) and they will move again when parts get weighed. **0.85/1.55 is retained**
on margin, and because the Onshape module is built to it — but that is a choice, and §7 says
so instead of hiding it.

Fifty-eight corrections are worth knowing about — 38's, 40's and 41's own numbered entries are
still only the bullets above. The first four changed the design; two of the
rest are checks that CONFIRMED it, which is its own kind of result. Each is the kind of thing
that silently recurs:

1. **Actuator packaging never set the airframe diameter** (§4). The original model assumed
   the servo body points inward; the output shaft is on a large face, so the servo lies
   flat and packaging is not binding at all.
2. **The canard hinge sign was inverted** — hinge aft of the panel CP is divergent, not
   self-centring. Now at 0.20c, forward of the 0.25c CP, and `hinge_moment()` returns a
   signed value so it cannot hide again.
3. **Nose ballast is required, not optional** (§7.1). Real 9 g servos removed ~180 g from
   ahead of the CG and took P(SM<1.0) to 1.8%. The 35.4° sweep briefly retired this — swept
   canards are less destabilising and the bare vehicle dropped to 0.7% — but sharpening the
   taper to 0.40 put the authority back and the risk with it, so it is 1.2% again and
   ballast is required once more. About 25 g is the minimum; 100 g is the design point.
   Canard authority and static margin are the same knob seen from two ends.
4. **The baseline used to live in six places and drifted from the docs.** It now lives
   only in `design/configure.py`. Do not copy those numbers into a script.
5. **The recovery bay is 4.5 cal because it was checked, not because it was typed.** It
   *was* just typed — nothing verified it until `recovery.check_packing()` existed. The
   first run of that check said the bay was 11 mm short and the airframe was briefly
   lengthened to 5.1 cal on the strength of it. **That was wrong, and the way it was wrong
   is worth remembering**: packed volume was estimated as budgeted mass ÷ assumed bulk
   density, and the budget carries a 280 g main against a real Iris Ultra 60" Compact at
   193 g. Two guesses multiplied together manufactured a shortfall that is not in the
   hardware. With the vendor's published pack volumes the chutes need 4.33 cal and fit
   with 13 mm to spare. The airframe was right all along; only the confidence was missing.
   **Do not change frozen geometry on the strength of an estimate when a published number
   is ten minutes away.**
6. **`check_flat_mount()` modelled the servo turned 90°.** It stacked the 23.5 mm body
   length around the circumference where the build puts 16.8 mm, overstating the arc
   requirement by a third — 106 mm against a true 79 mm. Both orientations fit, so no
   conclusion moved, but the wrong figure had already propagated into three documents
   before anything caught it. `check_bellcrank()` always had it right; they now agree.
7. **The canards had no sweep parameter at all.** `sweep_length` was hardcoded to a
   symmetric-taper trapezoid while the aft fins had a real `aft_sweep_cal` — so the canards
   sat at 7° against the aft fins' 35.4° and the vehicle read as two different designs.
   That default was also the maximum-authority shape (symmetric taper puts the mid-chord
   line at zero sweep), so matching the aft fins costs 12.5% of lateral authority: 2.08 →
   1.82 g, 450 → 394 m of crossrange. It buys static margin, torque margin, and a vehicle
   that looks like one object. `canard_sweep_cal = None` now derives the angle from the aft
   fins so the two cannot drift apart. **The hinge sign does not change with sweep** —
   hinge and panel CP are both referenced to the MAC — but the hinge STATION moves a long
   way — 57.2 → 68.3 mm from the module forward face — which is why the CAD had to be
   rebuilt. That rebuild is **done** (`docs/05`), and it turned up two Onshape bugs worth
   knowing: a wall cut that landed exactly on both faces and so cut nothing, and a circular
   pattern that silently dropped the material assignment on all nine copies.
8. **Taper was 0.70 because nothing had tried anything else.** Sharpening it to 0.40 (root
   grown to 0.85 cal to hold panel area at 3188 mm²) recovers most of what the sweep cost —
   1.82 → 1.96 g, 394 → 424 m — because CNa rises as the tip unloads. Root and taper are
   now set as a PAIR and must stay that way, or the area moves and every study downstream
   is invalidated. The price is flutter: the longer root chord drops the canard margin from
   5.42× to 4.46× at fixed 3.0 mm thickness. Still ~3× the requirement, but this is now the
   number to watch if the panel ever gets thinner.

9. **A bounding box has no output shaft, and that is not a small thing.** The servo was
   modelled as a mass-tuned block for long enough that two of its properties were never
   checked, because a block does not have them. The KST drawing says the output shaft is
   **6.14 mm from one case end, not centred at 11.75** — `docs/05` had flagged the centred
   assumption as "unconfirmed", and it was wrong — and that the shaft runs along the
   **16.8 mm axis**, so a radial output shaft spends 16.8 mm of tube radius and stacks only
   8 mm around the circumference. Every document said the reverse, which describes a servo
   whose shaft leaves its narrow edge. Both orientations fit and the packaging conclusion
   does not move, but the **central void goes from 45 mm to 17 mm** once the cable boss is
   counted, and that void is where the wiring and any pass-through structure live. (It is
   ⌀12.17 now: correction 11 moved the servos 4 mm inboard, and `check_flat_mount()` was
   given the servo's real seat so it measures the void instead of budgeting for it.) The
   pattern here is the same one as correction 1 and correction 6: **the actuator keeps
   being modelled as a shape rather than as a mechanism, and every time, the thing that was
   wrong was the bit the shape could not represent.**
10. **The interference sweep needed a mechanism, not a calculation — and then barely needed
   the sweep.** Once the canards could actually turn, the answer fell out of the
   arrangement: the hinge axis is radial and the shaft is coaxial with it, so the shaft
   sweeps nothing; rotation about a radial hinge preserves each panel point's distance from
   the rocket axis, so a panel that starts outboard of the tube stays outboard at every
   deflection; and the servos are entirely inboard of the wall while the panels are
   entirely outboard, so the two never share a radius. Nothing fouls. **What the sweep did
   turn up were two FITS that a static model cannot express**: the wall pass-through is
   ⌀5.000 against a ⌀5.000 shaft, because it reuses the shaft's own sketch — right for
   position, wrong for fit, and invisible to any interference check because zero clearance
   is not an interference — and the servo spline reaches only **0.185 mm** past the panel
   root face, so direct drive from the spline is not geometrically available and the
   spline-to-shaft coupling is an unmodelled design decision. **Both are closed by
   correction 11, and the sentence above about the servos and panels never sharing a radius
   is where the third defect hid: the SHAFT shares a radius with both.**
11. **The two open fits were one problem counted twice, and there was a third underneath.**
   Closing correction 10 started by asking what the shaft was actually made of. It was a
   **solid** ⌀5 rod from R 29.400 to R 40.200 — the API returns 212.058 mm³ against 212.058
   for a solid cylinder, so nothing had ever been cut away for the servo — while the
   servo's output face sat at R 37.185 with its case running inboard from there. **The
   shaft and the servo occupied the same space: 3.015 mm inside the output spline, 7.785 mm
   inside the case.** A hard clash, at zero deflection, in a model whose interference check
   had been signed off. The sweep did not see it because the sweep asked whether *rotation*
   caused a collision, and its answer to the question it asked was correct. The R 29.400
   was a leftover — the inboard face of the obsolete servo *block* — which is the lesson:
   **superseding a part does not supersede the dimensions that were taken from it.**

   The three defects share one cause. Between the servo's output face and the panel root
   there were **3.015 mm of radius and the airframe wall took 2.300 of them**. So there was
   no room for a bearing and therefore no bearing, no room for a coupling and therefore no
   coupling, no room for clearance and therefore none of that either. A LAYOUT problem in
   three tolerance costumes, and no fit callout fixes it.

   What made it visible was **the panel normal force, which nothing had ever computed**.
   The hinge moment is 0.0599 N·m — small, which is exactly why a 9 g servo is enough,
   because the hinge sits 2.4 mm from the panel CP. The same panel makes **25.4 N** at a
   bearing 29 mm away, so **0.734 N·m** of bending. *Reading only the hinge moment is how a
   hinge ends up with no bearing in it.* And peak pressure under an overhung load goes as
   1/L², so the 2.3 mm of wall available was not a slightly worse bearing than a 6 mm one —
   it was 175 MPa against an 80 MPa allowable.

   Fixed by moving the **servo** 4.000 mm inboard rather than the panel: the panel is
   frozen aerodynamics, the central void is a budget line. The shaft is now a ⌀6 sleeve
   from R 33.485 that stops at the servo's output face; the wall bore is a ⌀7.975 seat
   (**⌀8 H7 since correction 16**) carrying **its own dimension**, so it cannot track the
   shaft again; a ⌀6/⌀8 × 6.0 plain bearing takes the bending at 3.4× margin and the spline
   socket engages 91% of the spline (**that socket is superseded by a bought horn —
   correction 16**). Cost: central void — every band lost the same 8 mm, ⌀20.17 → ⌀12.17 over the
   8.2 mm where the cable bosses sit and ⌀40.77 → ⌀32.77 alongside the cases — plus 1.2 g
   and 1.3% of module roll inertia. **No control conclusion moved.**

12. **The last link was the hard one, and the answer was that the panel is made
   differently.** Correction 11 left the **sleeve-to-panel joint** open — a ⌀6 shaft cannot
   simply enter a 3.0 mm panel. It is the *hard* end of the load path, not the easy one:
   every number in the hinge stack shrinks going inboard because the bearing takes the
   couple out, and going outboard the moment is at its maximum, **0.721 N·m into 3.0 mm of
   G10**. Three of the four candidate joints lose to something already frozen rather than to
   structure — a root boss needs 9 mm of panel thickness and t/c drives flutter; a clevis
   stands proud of the panel in the fastest flow it sees; a one-piece aluminium panel adds
   154 g aft of a CG that already needs 100 g of nose ballast. The winner is a **1.8 × 14 mm
   tang, 30 mm into the root**, tang 2.9× and skin 2.9×, deliberately balanced.

   The finding worth keeping is not the tang. It is that **a 1.8 mm slot 25 mm deep into
   a 3.0 mm plate is a 14:1 blind cut and nobody can machine it**, so the panel becomes a
   **0.6 / 2.0 / 0.6 bonded laminate** with the core cut away (1.8 mm at first, which is
   not a stocked sheet — see correction 16). Same planform — the answer to "how does the shaft meet the panel" turned out to
   be a *manufacturing* change, and it would not have surfaced from any stress number.

14. **The tang was sized against stress, and the binding constraint was geometry.** The
   first version of correction 12 chose 1.8 × 14 × 30 and argued that depth was free —
   slot pressure goes as 1/L², so deeper is better and costs nothing. True, and the wrong
   axis. **The panel is swept 35.4°, so its leading edge runs aft 0.71 mm per mm of span**
   while the tang stays in a fixed axial band about the hinge axis, because it is the end
   of a shaft that turns about that axis. 30 mm of depth left **2.26 mm** of panel ahead of
   the tang. Worse, the "60% of chord" rule meant to bound it **allowed 40.5 mm, where the
   tang stands 5.18 mm proud of the leading edge** — a rule that admits an unbuildable part
   reads like a check and is worse than none.

   Now 1.8 × 11.9 × 25.5, with **6.15 mm** of leading edge and 2.5× on both the skin and
   the tang.

   **And there was a datum error underneath, which only reading the CAD caught.** The first
   fix read 5.50 mm of clearance where the truth was 5.14: `engagement` is measured from the
   panel root face at R 40.200, the planform's sweep and semispan from the theoretical root
   at the tube surface, R 39.700, and the 0.500 mm standoff between them was being ignored.
   The analysis agreed with itself and disagreed with Onshape, where panel 0 runs R 40.20 to
   107.19 — and 107.19 is 39.700 + 67.490. `RootJoint` is now indexed by radius throughout,
   which is what `HingeStack`'s docstring had already said to do.
   The old tang is kept and exercised: **every stress margin in it is better than the
   selected joint's and it is still not buildable**, which is the only case in this project
   that fails on geometry while passing on strength.

   A second bug fell out of writing the check: `slot_chord_fraction` divided engagement by
   the root **chord** when the tang reaches along the **span**. It returned the right number
   anyway, because `canard_root_cal` and `canard_semispan_cal` are both 0.85 and the two
   lengths are both 67.490 mm — and it would have silently read the wrong dimension the
   moment either moved. Same class of error as the sketch that measured to a circle's
   tangent. Found only by trying to build the thing in CAD, which is the general lesson:
   **the model agreed with itself right up until geometry had to exist.**

13. **The tube passed by three orders of magnitude, and the one number that did not is the
   one nobody was worried about.** `check_hinge_stack()` had emitted *"check the tube, not
   just the hinge"* since the hinge stack went in and nothing had. Four ⌀8 bores at one
   station remove 13.2% of a 79.4 × 2.3 tube's circumference; net section runs at **256×**,
   torsion 348×, shell buckling 434×. The airframe was never the risk.

   **The bearing seat is, at 3.2×** — and only because the housing collar does not exist.
   3.700 mm of the 6.0 mm bearing sits inboard of the tube ID, so with no collar the 2.3 mm
   wall holds it alone at 109 MPa; with a PETG-CF collar, 25.5 MPa and 14.5×. (This
   line read "17.4 MPa and 21.3×" until correction 19 asked what the collar was made
   of.) Peak pressure goes
   as 1/L², so those are **6.7× apart**. The printed bay was already blocked on bracket
   hardware; it is now blocked on something with a number attached. Two caveats stated
   rather than buried: the allowables are G-10 *sheet* and a filament-wound tube is not
   sheet (**under 4×, go get the real datasheet** — the seat is under it), and **global
   airframe beam bending under a gust is still not modelled anywhere in this project.**
   `design/tube_section.py` is the first structural model it has, and it runs at trim.

15. **A failing joint was reporting a pass, and only a buyability question found it.** The
   skin over the tang slot was computed as `(panel − tang)/2`. The slot is the tang **plus a
   bond line on each face**, so the real skin was 0.5 mm where the model said 0.6 — and skin
   stress goes as 1/t², so the joint sat at **1.69× against a 2.0× requirement while
   reporting 2.5×**. What surfaced it was not a stress review. It was being asked which G10
   sheets to *order*, which forces the stack to be expressed in thicknesses that exist.
   **"What do I buy" is a different question from "what is optimal", and it finds different
   bugs.**

16. **The panel is a laminate of two stocked sheets, and the shop is a 3D printer.** The
   0.6/1.8/0.6 stack was dead twice over — 1.8 mm G10 is not sold anywhere, and it was the
   thickness that produced correction 15. Now **0.6 / 2.0 / 0.6, 3.2 mm total**, the middle
   sheet cut away at the root so the slot is never machined at all. `canard_thickness` moved
   3.0 → 3.2, a frozen parameter changed for a manufacturing reason: flutter margin improves
   4.46× → 4.92×, static margin improves 2.03 → 2.04 cal (the 9 g lands forward of the CG),
   and crossrange gives up 1%, 424 → 419 m. Still feasible, no violations.

   Three more things fell out of taking "I have to buy this" seriously:
   - **The ⌀7.975 bearing seat is not a reamer that exists.** It is ⌀8 H7 now — the most
     ordinary reamer there is — and the press interference comes from the bushing being
     supplied oversize, which is how polymer bushings are actually fitted.
   - **Do not cut the servo spline.** A ⌀4 mm 15T internal spline in a 0.8 mm wall is
     specialist broaching; a servo horn arrives with it already cut for a few dollars. Safe,
     because the bearing sits outboard of the coupling and takes all the bending, so the
     joint carries torque only — 0.520 N·m at stall.
   - **The commercial servo frames do not do what the BOM claimed.** Hyperflight
     SRB-KST-X08 and the IDS/LDS frames are RC-glider *linkage* hardware; their counter
     bearing supports a swinging arm, not a shaft coaxial with the servo output. The
     third-bearing frame is 50 × 37 × 9 mm against a 23.5 × 8 × 16.8 servo, so four of them
     inside a 74.8 mm bore is its own problem. Dropped. Our own wall bearing already does
     that job, in the right place.

17. **The printed bay is unblocked, and it is the best-value part in the module.** It was
   held on "picking real bracket hardware", and correction 16 removed the bracket. The
   collar on it carries 3.700 mm of the 6.0 mm bearing — worth **3.4× → 14.5×** on the
   bearing seat, because peak pressure goes as 1/L² *and* because load goes where the
   stiffness is (correction 19). The build order is the part to get
   right: print the collar bore undersize, bond the bay in, then ream **⌀8 H7 through the
   wall and the collar in one pass**, so concentricity is a property of the operation rather
   than a tolerance held across two parts. A pinched bearing is a mechanism failure, and no
   margin in these documents protects against it.

18. **The bearing got built, and building it found a laminate that could not be ordered.**
   The Onshape `/features` quota came back and the queued work went in: the bearing Part
   Studio (volume checked against the analytic annulus to 0.001 mm³, which is the only proof
   the bore actually cut — a solid slug reads 301.593 instead of 131.947), the ⌀7.975 → **⌀8
   H7** seat correction from correction 16 finally applied to the CAD, and four instances
   placed in `Assembly 1`. Module mass 276.239 → 276.999 g, roll inertia +0.15%. **Nothing
   in the flight model notices, and that is the correct result** — the bearing was never a
   mass part, it is a load-path part.

   Two things worth keeping from it:
   - **`scripts/hinge_report.py` printed the panel as a `0.6/1.8/0.6` laminate**, which sums
     to 3.0 mm against a 3.2 mm panel. It was printing the **tang** as the middle layer
     instead of the **slot** — they differ by the two 0.1 mm bond lines. `design/hinge.py`'s
     own docstring said the same. The docs here were right and the code was wrong, which is
     the opposite of this project's usual rule, and it only matters because these three
     numbers are *sheets you buy*: acting on the printout would have ordered a 1.8 mm sheet
     that is not sold, to build a panel 0.2 mm too thin. Both fixed; the report now names
     the slot and the tang separately and states that the layers must sum to the panel.
   - **A mass guard that trips on an intended change is doing its job.** `make_hinge_stack.py`
     refused the bore correction because Part Studio mass read 276.227 g against a
     `MASS_BEFORE_G` of 259.856 — a stale constant from before the tang and the 3.2 mm
     panel. The geometry was fine. The constant now carries its own history in a comment and
     the tolerance stays tight deliberately: a guard loose enough never to trip is a guard
     that will not catch the circular pattern dropping materials, which is the failure it
     exists for. **A rise is as suspect as a fall until you can name the geometry.**

19. **The printed bay is built, and building it corrected the number that justified it.**
   `design/bay.py`, `scripts/bay_report.py`, `cad/canard_bay.fs`, `scripts/make_bay_cad.py`.
   One printed part, **PETG-CF, 39 g, 41.5 mm long**, holding four servos and four bearing
   collars; plus eight small retainer bars. It is in `Assembly 1` at identity, because it
   was drawn in the module's own frame.

   **The collar is worth 3.4× → 14.5×, not 3.2× → 21.3×.** Every document here priced it by
   putting the whole 6.0 mm bearing length into `p = 6M/(dL²) + N/(dL)` — a formula for ONE
   material. The seat is 2.300 mm of G10 and 3.700 mm of printed plastic, and **a rigid pin
   shares its couple out by stiffness, not by length**. A soft collar simply moves aside and
   the load walks back into the G10. `design/bay.py` models it as a Winkler foundation with
   a piecewise modulus, and it reduces exactly to the old formula when both materials match
   — there is a regression assertion for that, because a generalisation that cannot recover
   the case it generalises is not worth trusting.

   | collar | E, GPa | peak in wall | wall margin | effective seat |
   |---|---|---|---|---|
   | none | — | 109.0 MPa | 3.4× | 2.37 mm |
   | PETG | 1.7 | 37.1 MPa | 10.0× | 4.08 mm |
   | **PETG-CF** | **4.5** | **25.5 MPa** | **14.5×** | **4.93 mm** |
   | PA6-CF | 6.0 | 23.3 MPa | 15.9× | 5.17 mm |
   | *as stiff as G10* | *18.0* | *17.3 MPa* | *21.4×* | *6.00 mm* |

   **Build it anyway** — 3.4× → 14.5× is still the largest margin improvement anywhere in
   this hinge. But the bay is chosen on STIFFNESS, not strength: every candidate is strong
   enough, and they differ only in how much of the collar's benefit they actually deliver.
   Plain PETG passes everything if there is no hardened nozzle.

   Three more things came out of drawing it:
   - **No bought servo horn fits, and correction 16 says to buy one.** There is
     **0.515 mm** between the servo's output face and the bearing; outboard of that the hole
     is the ⌀6 bearing bore. The thinnest 15T ⌀4 horn hub is ~⌀7.4 × 4 mm. Nothing is
     mis-analysed — `design/hinge.py` never adopted the horn and still models and checks the
     broached ⌀4.4 × 2.9 socket at 29.9 MPa — but a builder following these documents would
     find out with four servos in hand. **The coupling is unresolved and it is not a bay
     problem**: no bay geometry fixes it. Either the shaft's spline gets broached or EDM'd
     with the rest of the part (it is already the one custom-machined piece), or the servo
     moves further inboard, and only ~2 mm of that is available before the four cable
     bosses collide.
   - **The servo is clamped, not screwed through its own flange.** Its lug holes sit 1.5 mm
     beyond the case ends and the tray window has to clear the case, which leaves a
     **0.62 mm ligament** — a perimeter and a half, which a slicer may not fill. The load
     does not go through it, so this is printability rather than strength, but "there may or
     may not be material there" is not a thing to build on. A printed bar clamps each end of
     the flange with 2× M2 into heat-set inserts, which also means a servo can be changed
     after the bay is bonded in — and the bay never comes out again.
   - **The bay would have clashed with the servo's own flange**, bosses and flange both
     wanting R 26.935→27.935. Found in CAD, not in the model, and invisible in an end-on
     view because the tray hides it. Fixed with a flange relief; `design/bay.py` now carries
     a clearance table so it cannot come back.

20. **The mass budget carries 240 g where the CAD now measures 63 g, and that is yours to
   decide.** `design/mass.py` has `canard shafts/bearings/sled = 4 × 0.030 + 0.120`, a
   placeholder from before any of it existed. Measured: 4 shafts 23.5 g, 4 bearings 0.8 g,
   bay and bars 38.6 g — **62.8 g**. The 177 g of difference sits at station 0.507 m, which
   is *forward* of the 0.800 m CG, so deleting it moves the CG aft and **reduces** static
   margin from 2.03–2.53 cal. That is probably a good thing (less weathercocking, more
   crossrange) but it is a vehicle-level change to every number in §1, so **nothing has been
   changed**. What the placeholder still legitimately covers is wiring, connectors,
   fasteners, epoxy and the aft gas seal — call that 40 g, not 177 g.

21. **The coupling is closed, and correction 16 was wrong about how.** Correction 16 said
   "do not broach the spline, buy a horn". Correction 19 found that no horn fits. Both were
   circling the same real constraint: **broaching a 15-tooth socket into a 0.95 mm wall is
   specialist, and every bought female-spline part is ⌀7 or larger against 0.515 mm of space
   and a ⌀6 journal.** The way out is neither.

   **Do not cut teeth — cast them.** Drill the shaft's inboard end **⌀4.100 × 3.20**, a
   plain round hole 0.050 mm on the radius over the spline's crests. Fill it with anaerobic
   retaining compound and push it onto the spline. The compound cures in the tooth valleys
   and *becomes* the female spline: fifteen keys formed by the very part they mate with, so
   they fit by construction. One drilled feature, on a part already being turned.

   | | |
   |---|---|
   | adhesive shear | 6.79 MPa against 17 MPa — **2.50×**, computed as if the socket were smooth |
   | the fifteen cast keys | 29.9 MPa of bearing if they carried it all — **deliberately not counted** |
   | shaft wall in torsion | 15.7 MPa — 10.2× in 6061-T6 |
   | reservoir | 0.30 mm past the engagement, so the blind hole does not hydraulic-lock |
   | serviceable | releases at ~250 °C — the reason for a retaining compound rather than epoxy |

   Allowable **only** because the coupling carries torque and no moment: the bearing sits
   outboard and takes all 0.806 N·m of panel bending, and this joint sees 0.520 N·m of servo
   stall. An adhesive in a bending path would be a bad idea. This is not one. Cut in CAD by
   `scripts/make_spline_socket.py`; `cad/canard_articulation.fs` gained `canardSplineSocket`.
   **Prime the bore** — 6061 is a passive metal and anaerobics need an activator on it.

22. **The shafts were modelled in stainless steel, and every document said 6061-T6.** The
   CAD carried "300 Series Stainless Steel" — 7850 against 2700, **5.86 g a shaft instead
   of 1.90** — while docs/04, docs/05 and an explicit instruction all said aluminium. Only
   a passing remark in `design/materials.py` agreed with the CAD, and it was never a
   decision. Settled on **6061-T6**: better margin (8.0× against 7.0× on sleeve bending),
   15.4 g lighter across four shafts at nearly the module's full radius on the roll axis,
   and far easier to cut a 1.8 mm tang and a 0.95 mm socket wall into.

   **How it hid for months is the transferable part.** Nothing ever read the density back.
   The material was set from an Onshape *library* entry, and a library material returns its
   density as `0` through the metadata API — so an audit that reads part metadata sees
   nothing wrong. What found it was `scripts/make_spline_socket.py` predicting its own mass
   change from the model's OWN measured density rather than from a constant, and printing
   that density in passing. **A safety check that reads what is actually there, instead of
   asserting what it expects, finds things it was not looking for.** Custom materials are
   now used throughout for exactly this reason.

   It also very nearly cancelled the printed bay: +38.6 g of bay, −15.4 g of shaft, so the
   module total moved 276.999 → 299.776 g and looked unremarkable. **A total is a bad place
   to look for an error.**

23. **An interference audit found six modelling defects that every other check passed.**
   Asked to go through the details properly, the useful move turned out to be Onshape's own
   assembly **Check interference** — which the REST API does not expose (`/interferencecheck`
   404s) and which nothing in this project had ever run. It reported **17 interfering pairs**.
   All six causes were invisible to part count, to mass, to the `evaluate()` violations, and
   to the axis-aligned bounding box.

   | what | why it was invisible |
   |---|---|
   | **Tang modelled inside the tube wall**, ×4. Its 1.0 mm union overshoot started the blade at R 39.200 in a wall running 37.400 → 39.700 | the tang is unioned *into* the shaft, so the shaft's bounding box never changed |
   | **Collar boss buried in the tube**, ×4. A flat-ended boss on a *radial* axis has its rim at `hypot(reach, OD/2)`: reaching R 37.250 put it at **37.730**, inside a bore of 37.400 | max X was 37.250 and looked perfect. **Radius is not a coordinate a bounding box knows** |
   | **Retainer bar buried in the servo**, ×8, 20 mm³ each. The flange's inboard face is only exposed in two 3 mm bands off the case ends; a bar long enough to seat an M2 head overran them by 1.7 mm | nothing measured the bar against the case |
   | **Collar bore modelled AS-PRINTED** ⌀7.500 with a ⌀8.000 bearing inside it, ×4 | both numbers were individually right; the model was carrying a manufacturing intermediate |
   | **Bearing bore ⌀6.000 on a ⌀6.000 shaft** — the design's own 0.030 mm running clearance was never modelled | *"zero clearance is not an interference"* — this project's own lesson, repeated one part further out |
   | **Four ⌀12 spikes 22 mm long** through the airframe, from a half-applied rebuild | see below |

   Fixed: tang overshoot 1.0 → **0.4 mm** (now a parameter, not a constant); collar boss stops
   at the shell **bore** plus 0.5 mm rather than reaching the OD; the retainer is a **dog bone**,
   2.6 mm across the flange and 4.7 mm at the screws; the collar bore carries the **as-reamed**
   ⌀8.000; the bearing bore is **⌀6.030**. **Check interference now reports none, across all 34
   instances.** `design/bay.py` grew a collar-rim check on RADIUS and a bridge-vs-case check, so
   none of these can come back silently.

   **The shaft's own bending was also being checked in only one place.** The spline socket makes
   the shaft hollow *inside the bearing*, and `hinge_loads()` checked the solid section at the
   tube wall on the strength of a comment. `shaft_stations()` now checks both, integrating the
   bearing reaction to get the real internal moment: tube wall 34.4 MPa (8.0×) still governs
   against the socket end's 23.0 MPa (12.0×) — **but at about 4.5 mm of socket depth it stops
   governing**, and nothing would have said so.

24. **Three Onshape workflow facts that cost the most time, recorded so they cost it once.**
   - **A feature's Feature Studio namespace is IMMUTABLE.** Editing new FeatureScript into an
     existing feature is refused with *"Feature does not match"* — with and without
     `serializationVersion`, with `rejectMicroversionSkew` both ways, and with no microversion
     at all. New source can only reach a feature by **deleting and re-adding** it.
   - **Rebuilding a Part Studio orphans every assembly instance of it.** Onshape *heals* the
     orphan to an **empty `partId`**: it keeps its name and its transform, still lists in the
     tree, contributes no mass and no geometry, and puts any rigid group holding it into ERROR.
     There is **no instance-delete route on the API**, so the cleanup is manual. Hence the rule
     now enforced by `make_bay_cad.py`: **finish a Part Studio before putting it in an assembly.**
   - **Adding a parameter to a custom feature silently defaults it on existing instances.** A
     half-applied rebuild left `collarOverlap` at Onshape's spec default of **25 mm**; the studio
     regenerated `OK`, kept its part count and its part names, and grew four ⌀12 spikes 22 mm
     long straight out through the airframe. Only the volume check caught it — which is why
     `verify()` compares volume against `design/bay.py` rather than counting parts.

25. **The aft gas seal was never a seal, and the hole in it is what sized it.** `docs/05`
   carried "a bulkhead between this module and the recovery bay, sealing a bore this part
   deliberately leaves open for wiring. Never sized" for six months. Read that and the part
   sounds like a gasket — something whose requirement is gas tightness. It is the **piston
   the ejection charge pushes on to separate the airframe**, and then the **anchor the main
   parachute pulls on when it opens**. Gas tightness is its third requirement. Same error as
   correction 2 and correction 11: **a part named after its smallest load, and then sized
   against the number in its name.**

   The load case that governs is not the nominal flight. A 1.17 g charge sized on the
   compartment's geometric volume, released into the **15% of that volume the parachute
   leaves free** with the joint not yet moving, is **1642 kPa and 7213 N** — seven times the
   design pressure. That is the stuck-joint case, and it sizes the disc for a reason that is
   not caution: **the shear pins are the intended fuse, so the bulkhead has to be stronger
   than the fuse**, or the wrong part fails first. It costs two sheet sizes and 23 g.

   **The feed-through governs, not the plate.** At 4.0 mm the disc passes at 2.8× and the
   wire hole fails at 1.70×. The part is 4.8 mm because of the feature it is *named for*,
   and a bulkhead sized as though it were a bulkhead is not a sized feed-through.

   Three modelling choices, each nearly made the comfortable way, and the first two are the
   transferable part:
   - **Simply supported, not clamped.** A bonded disc is between them and they differ by
     1.6×; assuming the fillet into the answer is how correction 15's joint reported 2.5×
     while sitting at 1.69×.
   - **The hole is placed on one model and checked against the other.** R 22.6 mm is where a
     *clamped* plate's radial stress passes through zero; a *simply supported* plate has no
     such radius. The first version of this used the clamped field for both and printed
     **15×** where the honest number is 2.45×. **Using the favourable model where it helps
     and the conservative one where it does not is not conservatism, it is a bug**, and it
     is worth more attention than any single margin here.
   - **Kt 2.0, not 3.0.** 3.0 is a hole in a plate under *in-plane tension*; this plate is in
     *bending*, where the thin-plate value is about 1.8. Being wrongly conservative is not
     free — at 3.0 the disc goes to 6.4 mm to buy a margin against a stress that is not there.

   **This correction also got the vent path wrong, and correction 28 fixes it.** The
   original argument ran: the module has two faces it could breathe through, it must not be
   the aft one because that is where the charge fires, so it vents *forward* into the nav
   bay and therefore joins the altimeter's static volume. Every step is sound and the
   premise is false — see correction 28. It is left here rather than edited away because
   the reasoning is the interesting part.

   Three things it opened, all now closed: the **drogue's firing circuit** (a ⌀5 mm bonded
   conduit through the main compartment, priced in `recovery.py`), the **internal bulkhead**
   (correction 29), and the **venting** (correction 28).

26. **The BOM and the mass budget disagree by exactly one dual-deploy altimeter.** Found by
   asking a question that had nothing to do with structures — *where does the custom PCB
   go?* `docs/04` §5 lists nine avionics lines totalling **620 g**, including a 60 g
   commercial altimeter. `mass.py`'s `DEFAULT_AVIONICS_BUDGET` lists nine lines totalling
   **560 g**, and the missing one is that altimeter. Every other line agrees to the gram.

   It is not a rounding difference and the altimeter is not optional: it is the independent
   commercial part that fires the charges, it is what the seal in correction 25 is wired to,
   and flying deployment off the custom PCB alone is a different safety argument than the
   one these documents make. **APPLIED Aug 2026** — not treated like correction 20, because
   that one proposes *deleting* a contingency somebody might want and this one is a required
   part the vehicle carries whether or not the budget admits it. Leaving it out does not make
   the rocket lighter.

   | | before | after |
   |---|---|---|
   | dry / wet mass | 5.487 / 6.111 kg | **5.553 / 6.177 kg** |
   | dry CG | 0.800 m | 0.795 m (forward — the altimeter lands ahead of it) |
   | static margin | 2.04–2.53 cal | **2.10–2.58 cal** |
   | P(SM < 1.0) | 0.43% | **0.30%** |
   | apogee | 1376 m | **1358 m** |
   | max Mach | 0.530 | 0.524 |
   | one-sided crossrange at 8° | 419 m | **393 m** |

   Still feasible, no violations, and the stability numbers all move the *right* way. The
   one claim it did break is in `docs/00` §D6 and `docs/02`: **J449BS ranks 11th on
   crossrange among motors passing every constraint, not 9th.** The selection does not
   change — it was never made on crossrange rank — but the sentence was, and now says 11th.

   The transferable part is where it came from. Nothing in this repo cross-checks
   `docs/04` against `design/mass.py`; they are two lists maintained by hand, which is the
   exact condition that produced correction 4. **A question from outside the analysis found
   it in one minute, and no check inside the analysis would ever have.**

27. **The nav bay has never had a packing check, and the first one says it does not fit.**
   `nav_bay_cal = 1.6` was typed at the same time as `recovery_bay_cal = 4.5` and by the same
   hand. The recovery bay got `check_packing()` and an 11 mm scare; the nav bay got nothing,
   for a year, while it quietly became the answer to "where does the custom PCB go".

   `design/avionics.py` is that check. **152 mm of sled wanted against 103 mm available**;
   117 mm with the tracker and radio moved to the nose.

   **The modelling point is worth more than the verdict.** The obvious check — add up
   component volumes, compare against the bay's — gives 150 cm³ in 558 cm³ and says the bay
   is two-thirds empty. It is the wrong check. Boards mount on the two faces of a flat sled,
   and a flat sled in a round tube can only use the rectangle inscribed in the circle: at a
   60 mm sled the usable height is 44.9 mm, not 74.8, and nothing reaches the four corners.
   **The binding quantity is footprint on two faces, and the volume is real but is not the
   constraint.** Same class as reading the hinge moment and concluding a 9 g servo is enough.

   **Do not lengthen the bay on the strength of this.** Every envelope in it is an estimate
   for a part nobody has chosen, which is correction 5's exact configuration — an
   estimate-driven shortfall, acted on, that turned out not to be in the hardware. So it is
   an `evaluate()` **warning** and not a violation: `feasible` stays YES, and the warning
   prints at the top of `scripts/baseline.py` where it cannot be missed. A new field on
   `Evaluation`, because "the vehicle cannot fly" and "the vehicle as *estimated* has a
   problem" are different claims and the model had only one channel for them.

   In order of what it costs: **close D7 and measure** (nine datasheets, and the only thing
   that settles it); **move the tracker and radio to the nose**, worth 35 mm and no frozen
   geometry — and where a tracker belongs anyway, since its job is to still be working when
   nothing else is; **one end closure instead of two**, worth 12 mm if the nose shoulder or
   the canard module's forward face already does the job; **lengthen the nav bay** to 2.0 cal,
   +32 mm, which touches every number in §1 and is therefore last.

28. **A bay is a cylinder, and the third surface is the wall.** Correction 25 argued that the
   canard module has "exactly two faces it could breathe through", that the aft one is
   disqualified because the ejection charge fires there, and that the module therefore vents
   forward into the nav bay — joining the altimeter's static volume, and making a leak past
   the aft seal a pressure-sensor fault rather than a soot problem.

   Every step of that follows. The premise does not: the module vents **overboard through
   its own wall**, like every other bay in high-power rocketry, and that wall already has
   four ⌀8 mm bores through it. Two ⌀2 mm holes cost nothing and the whole chain goes away —
   the sense volume is the nav bay alone, the wiring pass-through gets **potted solid**
   rather than having to pass air, and a leak past the seal goes outside.

   **The framing failed, not any number.** *"It has two faces and one of them is
   disqualified"* is a complete-sounding argument that silently excluded the answer, and
   nothing inside it was ever going to catch that. Correction 1 is the same shape: the servo
   was assumed to point inward and every conclusion after that was sound.

   `design/venting.py` owns this, and it found one more thing by being written. It was built
   to size the static ports against **lag** — a bay that lags on the way down fires the main
   below the 200 m it was set for, which is the failure with no margin under it. **Lag does
   not size these holes, by a factor of about 300.** The model asks for 1.35 mm² and
   convention drills 24.1. So the ports are set by blockage tolerance, by the ejection
   transient, and by what a person can drill and deburr by hand — none of which is modelled
   — and *"the bay must breathe fast enough"*, which is the reason everybody gives for these
   holes, is not the reason. A check that confirms is its own kind of result.

29. **`recovery.FILL_LIMIT` sets the design pressure of every bulkhead in the rocket.**
   Sizing the internal bulkhead should have been a second, easier pass of correction 25's
   model. It was, and it printed something neither part's geometry explains: **both
   bulkheads see the same stuck-joint pressure**, 1668 and 1689 kPa, though one closes a
   1042 cm³ compartment and the other a 429 cm³ one.

   `check_packing()` gives every compartment the length its contents need *at the fill
   limit*, so every compartment leaves the same free fraction — 1 − 0.85 — whatever is in it.
   The charge scales with the geometric volume and the free volume scales with it too, and
   the ratio cancels. **The drogue compartment holds a quarter of the volume and is 1%
   worse.**

   So `FILL_LIMIT = 0.85`, chosen as a packing convenience — *"a bay packed to 100% is a bay
   that will not close on the launch rail with cold hands"* — is a **structural** parameter
   and nothing said so. Pack to 0.90 instead and every bulkhead load rises 50%, to 2502 kPa.
   `check_seal()` prints that sensitivity on every run.

   Two things about the part itself. It is the **only pressure boundary in the vehicle with
   no fuse**: the aft seal is protected by shear pins that go first by design, while this one
   is bonded into the tube at both ends of its load path, so a joint that sticks simply hands
   it the whole charge. For it the stuck case is not a contingency, it is the only case. And
   its **assembled stack is 10.8 mm against the 12.0 mm `BULKHEAD_THICKNESS` allowance** —
   which fits, and which was a typed number nothing had ever compared against a part.

30. **The tracker and the radio moved to the nose, and the nose turned out to be the one
   volume whose width is a function of station.** Correction 27 left the nav bay 49 mm short
   and listed four ways out. This is the second of them and the only one that costs nothing
   structural: **the telemetry radio and the independent GPS tracker now ride in the nose**,
   on the same threaded rod as the ballast, 20 mm behind it.
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

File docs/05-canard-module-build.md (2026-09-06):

# Canard module — CAD build sheet

Regenerate the profiles with `python scripts/make_cad_profiles.py`. They are written from
`design/configure.py`, so the CAD cannot drift from the analysis. If a dimension here
disagrees with something you remember, regenerate; do not retype.

## State of play — August 2026

Read this first if you are picking the CAD back up. Progress lives in the Onshape document
(`canard-control module`), not in this file — this is just a pointer to where things stand
so a fresh session doesn't have to re-derive it.

The document now holds **four** elements that matter:

| element | what it is |
|---|---|
okayimensions the shaft three times from three datums (6.14 from the case end, 7.64
  from the lug-hole line, 9.14 from the envelope end) and those datums are 1.5 mm apart
  exactly as the 23.50 / 26.50 / 29.50 stack requires, so the reading checks itself.
- **The shaft runs along the 16.8 mm axis**, so a RADIAL output shaft spends 16.8 mm of
  tube radius and stacks only 8 mm around the circumference. Every document here said the
  opposite — "8.0 mm radial, 16.8 mm circumferential" — which points the output shaft
  tangentially and cannot drive a radial hinge. Both orientations fit, so no conclusion
  moved, but the **central void is 21 mm, not the 58 mm the block implied**, and the wiring
  and any pass-through structure have to live in that void. (It is ⌀12.17 now: the servos
  moved 4 mm inboard to make room for the hinge bearing. See "The hinge stack".)

Both numbers now live in `design/packaging.SERVO_GEOMETRY`, read off the manufacturer's
dimensioned drawing, and `check_flat_mount()` takes the orientation from there instead of
guessing it.

**CURRENT as of Aug 2026**, rebuilt for the 35.4° sweep / 0.40 taper. Part Studio 1 has 13
features and 13 parts — the original 11, plus `Canard hinge mate connectors` and
`Canard deflection`, both from the Feature Studio.

**Done**, in feature-tree order: tube (`Extrude 1`, G10/FR4 1850 kg/m³) → `Hinge Plane`, an
offset from Top, now **68.27 mm** → one canard panel, root LE at **37.71 mm**, root 67.49 /
tip 8.9 / sweep 104.5, root 88.6, LE 42.2 deg (pointed delta, correction 63) → shaft sleeve, **⌀6 mm, R 33.485 →
40.200** on the hinge axis (`Sketch 3` / `Extrude 3`) → the old ⌀ = shaft wall cut, which
still reuses the shaft's own sketch and is now superseded
(`Extrude 4`) → servo envelope block, 23.5×8.0×16.8 mm, mass-tuned to 9 g via a custom
material "Servo mass override (9 g)" at 2849 kg/m³ rather than a direct mass override, since
no such field was found in this Onshape UI (`Sketch 4` / `Extrude 5`) → `Circular pattern 1`,
a FEATURE pattern of `Extrude 2/3/4/5`, 4 instances at 90°, axis on the tube's own circular
edge, **Reapply features ON**.

**Four bugs have been found and fixed in this model. Read them before touching it:**
- `Extrude 4` was cutting **nothing**. It ran blind 2.3 mm from a 37.4 mm offset, which is
  exactly R37.4→R39.7 — precisely coincident with both wall surfaces, so the boolean was
  degenerate ("would result in non-manifold body"), and in its original direction it cut
  *inward into the bore*, through air. It is now **Opposite direction, offset 36 mm, depth
  5 mm**, so it overshoots both faces cleanly. Never let a cut land exactly on a face.
- The circular pattern does **not** carry material assignments to its copies. All nine
  patterned parts had no material and contributed zero mass, so the module read 0.175 kg
  instead of 0.260. Assign material to the copies after every pattern, and check the total.
- **`Sketch 3`'s hinge dimension measured to the circle's TANGENT, not its centre.** It read
  `57.2 mm` while the shaft axis actually sat at 59.700 — off by exactly the 2.5 mm shaft
  radius. The dimension now references `tt9bc77TUdvp.center` and reads the true station.
- **The `Hinge Plane` drove nothing.** `Sketch 3` and `Sketch 4` are built on plane `JEC`,
  not on it, so the datum was decorative — editing its offset moved the plane and no
  geometry. Combined with the bug above, the physical hinge sat at **0.029 of MAC instead
  of 0.200**, which is a 4.4× hinge moment and a **0.82× servo torque margin against a 2.0×
  requirement**. Both sketches are now dimensioned to Z 68.27 directly. The Hinge Plane is
  still not a driving reference — treat it as annotation until someone wires it in.

**Orientation, since it looks wrong and is not:** Top plane is the module's FORWARD face and
+Z runs AFT. Because Onshape draws +Z up, the module renders nose-DOWN. It is correct — the
panel CoM measures Z = 83.307 mm against an analytical 83.310, where a flipped model would
read 59.61 — but it is worth knowing before you mate this into an assembly.

**Loose ends on what's built:**
- The obsolete servo block's radial centering was off by ~0.09 mm. It no longer matters —
  the block is superseded — but the same trap applies to anything else dragged into place
  instead of constrained.
- **Both open fits are CLOSED.** See "The hinge stack" below. They turned out to be one
  problem counted twice, plus a third that neither of them mentioned.

**The hinge is now a mechanism, not a hole.** Both fits that this file carried as open —
the ⌀5.000-on-⌀5.000 wall pass-through and the spline's 0.185 mm of reach — are closed, and
closing them exposed a solid-on-solid clash the sweep had not been asked about: the ⌀5
shaft ran 7.785 mm into the servo case and 3.015 mm into its spline. The servo has moved
4.000 mm inboard, the shaft is a ⌀6 sleeve that stops at its output face, and the wall bore
is a bearing seat carrying its own dimension (⌀7.975 as first built, **⌀8 H7** in the CAD
since Aug 2026 — `make_hinge_stack.py --bore` corrects it in place rather than skipping it,
because a step that silently declines to apply a design change is how the CAD and the
analysis drift apart). Full argument and margins under "The
hinge stack" below; model in `design/hinge.py`. **The two items that left open — how the
sleeve meets the panel, and what four bores do to the tube — are closed too**; see "The
root joint" and "The tube at the hinge station".

**The four revolute hinge mates are IN** (Aug 2026), so `Assembly 1` is a mechanism and not
just a pose. `Canard 0 (+X) hinge` … `Canard 3 (-Y) hinge`, each pairing `tube{n}` with
`shaft{n}` from `canardHingeConnectors`, REVOLUTE. Mass and CoM did not
move (258.650 g, Z 75.122 mm), which is the check that the connectors really were
coincident — mating two connectors that are not coincident drags the geometry.

**They were in and they did not turn, and the mate limits were why** (Sep 2026 — correction
39 in `docs/01`). The four mates carried the ±8° deflection limit, and every attempt to
animate one came back *"Unable to compute any steps for this animation. Unable to apply
transform. Instance(s) may be constrained."* Nothing in the assembly explained it: all 36
instances sit in exactly one rigid group each and the groups do not overlap, only the tube
is fixed (correctly — it is ground), every feature regenerates OK, and both mate connectors
resolve to the right parts. **On these mates a limit does not clamp the rotation, it
abolishes it.** Measured by driving the mate through `POST /matevalues` after each edit and
confirmed against the animation itself:

| `limitsEnabled` | rotation limit | asked | got |
|---|---|---|---|
| false | — | +5° | **+5.000°**, and the animation plays |
| true | −8 … 8° | +5° | 0.000°, frozen — the error above |
| true | −60 … 60° | +5° | 0.000°, frozen |
| true | −360 … 360° | +90° | 0.000°, frozen |
| true | 80 … 100° | +90° | 0.000°, frozen |

So it is **not the width of the limit** and not a pose sitting outside one: a limit generous
enough to allow a full revolution freezes the hinge exactly as hard as ±8° does. It is not
the rigid groups either — suppressing `Canard 0 (+X) rotating group` and retrying changes
nothing. The trigger is `limitsEnabled` itself, on mates whose connectors come from a Part
Studio (`BTMPartStudioMateConnectorQuery`), and it applies to all four identically.

Onshape's own Edit-mate dialog reads and writes `limitAxialZMin/Max` for a revolute's
rotation limits — open the dialog and those are the numbers it shows — so **the browser did
nothing wrong when these were authored**. The other Z pair, `limitZMin/Max`, *is* drivable
with limits enabled but enforces nothing (driven to +12° against a ±8° limit without
complaint), so putting the deflection limit there would leave the Limits box ticked over a
limit that does not exist. This project has enough of those.

**Fixed by turning the mate limits off**, with `scripts/fix_hinge_mate_limits.py` (safe to
re-run; `--verify` drives all four and parks them at zero). The limit was never load
bearing: no script has ever read it, `scripts/canard_sweep.py` drives the Part Studio's
`deflection` parameter rather than the assembly mates, and the number that every analysis
actually reads is `DEFLECTION_LIMIT_DEG` in `design/configure.py`. What is lost is a
hand-drag guard in the browser; what is gained is the mechanism the assembly exists to
demonstrate. Mass 356.393 g and CoM Z 78.183 mm across the write, unchanged to the microgram
— a limit is not a pose.

**If you re-author these mates by hand, leave Limits unticked**, or the assembly goes back
to being a pose.

They were added **in the browser**, because the assembly-feature API still will not create
them. The useful discovery is that the restriction is on CREATION only: once the mates
existed, `POST /assemblies/.../features/featureid/{fid}` renamed all four from
`Revolute 1..4` without complaint. So the API can maintain a mate whose connector query
already resolves; it just cannot author that query. If these ever need rebuilding, expect
to place them by hand and script everything after.

In the UI the recipe is: expand `Canard module tube` in the instance list (its four mate
connectors are in quadrant order 0,1,2,3 — the status bar confirms it, the first reads
X 34.800 / Y 0.000 / Z 68.270), click the tube connector, ctrl/cmd-click the matching
`Canard shaft n` connector, check that the status bar reads **Min dist 0.000 mm**, then hit
Revolute. Tick Limits and enter −8 deg, **Tab**, 8 deg — clicking between the two limit
fields lands on the units autocomplete instead, and `Ctrl/Cmd+A` in that dialog clears the
mate connector selection rather than the text.

**Printed bay**: BUILT (Aug 2026) — see "The printed bay" below. It was previously recorded
as blocked, then as unblocked; it is now geometry. What follows is the note from when it was
unblocked, kept because the collar argument in it is still the reason the part exists.

 It was held on "picking real bracket
hardware"; the bracket turned out not to be needed — see docs/04 on why the commercial servo
frames were dropped — and the bay is printable now. **It is the last open item in the hinge
load path and it has a number on it**: the housing collar carries 3.700 mm of the 6.0 mm
bearing, worth **3.4× → 14.5×** on the bearing seat. See "How this actually gets built"
and "The printed bay".
The aft gas seal is SIZED as of Aug 2026 (see "The aft gas seal" below); the forward wiring
pass-through is still open as geometry, and it is the module's vent. The mate connectors the hinges
need exist in pairs on each hinge axis (`canardHingeConnectors`), the rigid groups either
side of each hinge exist, and **the mates are in** — see above.
`scripts/make_module_assembly.py` still
builds everything up to that point; its `revolute()` remains the record of what the API
would not do.

**The interference sweep is RUN.** `python scripts/canard_sweep.py` drives the deflection
through ±8° and reports clearances; images land in `out/cad/`. The answer is that nothing
fouls, and the reason is structural rather than numerical, which is why the check kept
feeling harder than it was:

- the hinge axis is radial and the shaft is coaxial with it, so the shaft sweeps nothing;
- rotation about the hinge preserves each panel point's distance from the ROCKET axis,
  because that distance is measured **along** the hinge axis. The panel starts outboard of
  the tube and therefore stays outboard at every deflection — worst case 40.228 mm against
  a 39.700 mm tube;
- the servos are entirely inboard of the wall and the panels entirely outboard, so the two
  sets never share a radius. Servo-to-servo gap is 44.1 mm at the seat radius (50.4 before
  the servos moved inboard).

**Read that last bullet again, because it is where the third defect hid.** Servos and
panels never share a radius — true, and irrelevant, because **the SHAFT shares a radius
with both**, and the shaft is what was overlapping the servo. A correct argument about the
wrong two parts. See "The hinge stack" below.

The 0.5 mm root standoff is therefore an assembly allowance, not the swept-clearance
allowance this file described.

## The hinge stack

The two "loose ends" above were closed in August 2026, and closing them turned up a third
defect that neither of them named. All three are the same problem: **between the servo's
output face and the canard panel root there were 3.015 mm of radius, and the airframe wall
took 2.300 of them.** No tolerance callout creates space that is not there.

The third defect. `Canard shaft 0` was a **solid** ⌀5 rod from R 29.400 to R 40.200 — the
API returns 212.058 mm³ against 212.058 for a solid cylinder, so nothing had ever been cut
away for the servo — while the servo's output face sat at R 37.185 with its case running
inboard from there. The shaft and the servo occupied the same space: 3.015 mm of it inside
the output spline, 7.785 mm inside the case. That is a hard clash, not a fit subtlety, and
**the swept interference check did not see it because the sweep asked whether ROTATION
caused a collision and this collision was already there at zero deflection.** The R 29.400
was a leftover: it is the inboard face of the obsolete servo *block*, which the real part
superseded without anything re-examining what had been dimensioned to it.

The decision, and it is one decision rather than three:

| | |
|---|---|
| Servo | moves **4.000 mm inboard**, output face R 37.185 → **R 33.185** |
| Canard shaft | ⌀5 solid rod → ⌀6 → ⌀8 → **⌀10 sleeve (correction 62), R 33.485 → 40.200**, with a ⌀4.4 × 3.2 deep 15T spline socket at its inboard end. **The socket is superseded** — buy a splined servo horn instead, see "How this actually gets built" |
| Wall bore | ⌀5.000 → ⌀7.975 → ⌀10 H7 → **⌀12 H7 (correction 62)**, on its own dimension, seating a **⌀10/⌀12 × 6.0** plain bearing. ⌀7.975 was superseded by ⌀8 H7 because it is not a reamer that exists; ⌀8 H7 was superseded by ⌀10 H7 to make the bearing pressure margin on a horizontal launch (docs/12 §9), and ⌀10 by ⌀12 when the canard went 1.30 → 1.45 cal (docs/12 §11) |
| Bearing | new. 6.000 long, 2.300 of it in the wall, **3.700 needing a housing collar off the printed bay** |

Why the servo and not the panel. Something had to move: a plain bearing that can carry a
25 N panel load on a 29 mm overhang needs about 4.5 mm of length, because the peak pressure
under an overhung load goes as **1/L²** — a 2.3 mm bushing in the wall is not a slightly
worse answer than a 6 mm one, it is 7× worse, and it fails at 175 MPa against an 80 MPa
allowable. Moving the panel outboard would work and would change frozen aerodynamics.
Moving the servo spends **central void**, which is a budget line. Every band loses the same
8 mm, because the whole servo moves: ⌀20.17 → **⌀12.17** over the 8.2 mm where the cable
bosses sit, and ⌀40.77 → **⌀32.77** over the 29.5 mm alongside the cases. The wiring has to
fit the smaller. 4.000 mm is the largest move the four bosses allow with a millimetre to
spare before they meet on the axis.

**The number that was missing was the panel normal force.** The hinge moment is 0.0599 N·m,
which is why a 9 g servo is enough — the hinge sits 2.4 mm from the panel CP. The same
panel makes **25.3 N** at a bearing 29 mm away, which is **0.718 N·m** of bending where the
shaft leaves the tube. Reading only the hinge moment is how a hinge ends up with no bearing
in it.

Margins on the selected stack, at q = 19.42 kPa and 9.19° of panel local alpha:

| | |
|---|---|
| Bearing peak pressure | 23.2 MPa, **3.4×** against an 80 MPa polymer plain bearing (iglidur G class) |
| Sleeve bending | 34.6 MPa, 8.0× in 6061-T6, 18.9× in steel |
| Spline engagement | 2.900 mm, **91%** of the 3.2 mm spline; sized by the servo's 0.52 N·m **stall** torque, not by the aero moment |
| Socket wall | 0.800 mm at ⌀6 — this, not strength, is why the shaft went to ⌀6. **⌀8 made it 2.000 mm and ⌀10 makes it 3.000 mm**, so both journal growths improved the dimension this row exists to protect |
| Running clearance | +0.030 mm, against **+0.000 before** |

`design/hinge.py` holds the model, `scripts/hinge_report.py` prints it to
`out/hinge_report.txt`, and `scripts/make_hinge_stack.py` applies it to Onshape (idempotent;
every write is followed by a part count, a feature-status sweep and a mass comparison).
Four API facts that cost time and are not in Onshape's documentation, so they are written
down. **An assembly feature id can contain a `/`** — `MwVg60P6xoYjGb/Tu` is one of the
rigid groups — so it must be percent-encoded into the `/features/featureid/{fid}` path or
the call 404s while looking exactly like a feature that is not there. **A limit parameter
that is UNSET reads back from `GET /features` as a non-null zero**, so the obvious round
trip — read a mate, change one thing, post it back — rewrites every unset limit as a hard
value; anything editing a mate should set what it means and null the rest. Then:
**there is no assembly interference-check endpoint** (`/interferencecheck` 404s on
v10), which is why the clash had to be found from part bounding boxes and a volume that
matched the analytic solid figure exactly; and **a `mateGroup` freezes its members**, so
the four servos could not be transformed until the five rigid groups were deleted, saved
verbatim, and posted back afterwards. **And the API throttle is PER-ENDPOINT, with a long window.** This is worth knowing before
you plan a CAD session. Onshape's 429 is not only a burst limit: `/partstudios/.../features`
carries its own multi-hour quota, and when it is spent the server answers with a
`Retry-After` measured in hours — **49699 s, just under fourteen**, on 2026-08-30 — while
`/parts/...`, `/assemblies/...`, `/massproperties` and `/shadedviews` all keep working
normally. So a session can lose the ability to read or write the feature tree while still
being able to measure and render everything.

`/features` is the expensive one because it returns the whole tree (161 KB here) and forces
a regeneration, and the scripts call it far more than they need to: `set_quantity()` fetches
it to read a parameter and `verify()` fetches it again to check status, so a single
dimension change costs two full trees. `canard_sweep.py` costs about eight per sweep.
**Caching the tree within a run, and trusting the POST response's own feature state instead
of re-reading, is the fix and has not been done yet.**

`design/onshape.call()` retries 429 and transient 5xx with exponential backoff — safe,
because a 429 means the request was rejected rather than applied, so a retried POST cannot
double-apply — but it **caps `Retry-After` at 300 s** and otherwise fails immediately with
the time the quota returns. A script that honours a fourteen-hour `Retry-After` literally
is indistinguishable from one that is working.

`scripts/baseline.py` now carries a one-line hinge-stack verdict so the fit cannot silently
regress, and the check is exercised against the **as-built** layout as well as the selected
one — it fails the as-built on five counts, which is the only evidence that it checks
anything.

**Two things the model still does not carry, deliberately:**

- The ⌀4.4 spline socket is **not cut** in the Part Studio, and is now superseded by a
  bought servo horn anyway; the shaft is modelled as its
  ⌀6 envelope. Cutting it needs a boolean scope that reaches the four patterned shaft
  bodies without also drilling the four obsolete servo blocks, which is not worth the
  risk to a working tree for a feature that changes no mass and no clearance. The socket
  is a manufacturing dimension, carried here and in `out/hinge_report.txt`.
- **The tang and its slot are not modelled either.** Same reasoning as the spline socket
  above: they are manufacturing dimensions, they change no mass and no clearance, and
  cutting them needs a boolean scope that reaches four patterned bodies without touching
  the four obsolete servo blocks. They are carried in "The root joint" below and in
  `out/hinge_report.txt`. **The panel becoming a laminate is not a CAD change either** —
  the solid is identical — but it *is* a build-sheet change, so it is written up rather
  than left in a script.

**Module mass properties, measured Aug 2026 — from `Assembly 1`, with real servos:**

| | |
|---|---|
| Mass | **0.25865 kg** |
| Volume | 133,510.6 mm³ |
| CoM | X 0, Y 0, **Z 75.122 mm** aft of the module forward face |
| Inertia about CoM | Ixx = Iyy = **581.280** kg·mm², Izz = **604.584** kg·mm² |
| Off-diagonals | zero — the four-fold symmetry check passing |

Measure this on the ASSEMBLY, not Part Studio 1: the servos are no longer in the Part
Studio, so a Part Studio measurement now double-counts the obsolete blocks and misses the
real parts. Against the envelope-block figures the CoM moved 0.95 mm aft and roll inertia
fell 2.2% (626.268 → 612.442), because the real servo's mass sits off its own body centre
and hangs 16.8 mm inboard rather than 8. `design/control.py` carries the new tensor.

Re-measured after the hinge rebuild below: the ⌀6 sleeve, the bearing seat and
the 4 mm servo move together cost 1.21 g and took roll inertia down 1.3% (612.442 →
604.584). Neither moved a control conclusion, which is the point of measuring rather than
assuming. The previous figures — 0.259864 kg, Z 75.090, 585.266 / 612.442 — are kept in
`design/control.py` as a comment for exactly that comparison.

That 0.25865 kg is against roughly 0.565 kg in the mass budget, and the gap is real, not an
error: the servo frames, outboard bearings and printed bay are not modelled yet. Re-measure
once they exist.

## The root joint — how the shaft meets the panel

Closed August 2026. This is the item the hinge stack left as "the next real design
decision, in the place the spline coupling used to occupy", and it is the **hard** end of
the load path, not the easy one: every number in the stack gets smaller going inboard,
because the bearing takes the couple out. Going outboard the moment is at its maximum —
**0.721 N·m at the panel root** — and it has to be handed into 3.0 mm of G10.

Four ways to make the joint. Three lose, and it is worth recording why, because two of them
look better than the winner until you price them:

| | |
|---|---|
| **Root boss** — thicken the panel root into a hub, bore it ⌀6 | Needs ~9 mm of local thickness. Panel is 3.0 and its thickness is **frozen aerodynamics**: t/c drives the flutter margin, which the 0.40 taper already spent from 5.42× to 4.46×. Rejected — it moves a frozen number to solve a joint problem |
| **External clevis** — a fork straddling the panel, cross-bolted | Structurally the best of the four and the easiest to build. It also stands proud of the panel surface, at the root, in the fastest flow the panel sees, on all four panels. Rejected on drag, and it invalidates the swept interference check |
| **One piece** — machine shaft and panel from one aluminium billet | The honest structural answer: no joint at all. +38 g per panel, **+154 g on the vehicle**, all of it aft of the CG, on a design that already needs 100 g of nose ballast to satisfy R1. Rejected on mass and CG, not on structure. Revisit if the ballast budget ever grows |
| **Tang in a slot** — the sleeve's end milled to a flat blade, bonded into the panel root | **SELECTED.** Spends no aerodynamics, no mass and no CG. It moves the problem into the one place with room: the *plane* of the panel, 67.5 mm of root chord, rather than its 3.0 mm thickness |

**The selected tang: 1.8 × 11.9 mm, 25.5 mm into the root.** The three numbers are coupled
and none is free:

- **Thickness 1.8** sets the skins at 0.6 mm each. Thicker tang, stronger tang, weaker
  skin — and the skin's stress goes as 1/t², so the trade is sharp. This is the one number
  that did *not* move when the leading-edge constraint turned up, which is why the panel is
  still a laminate.
- **Width 11.9** is paid for twice. Wider carries more (σ goes as 1/w) but its skin spans
  further, so skin stress *rises* with width — and it pushes the tang's forward corner
  towards the leading edge.
- **Engagement 25.5**, and **this is the one that was wrong twice.** See below.

| | |
|---|---|
| Tang bending | 111.7 MPa — **2.5×** in 6061-T6, 2.1× in 303 stainless, 5.9× in 4140 |
| Skin over the slot | 195.1 MPa — **2.5×** against a 480 MPa flexural allowable |
| **Leading-edge clearance** | **6.15 mm** at the tang tip, against a 5.0 mm minimum |
| Slot bearing | 0.64 MPa from bending, 0.86 MPa from **stall** torque — 428× |
| Bond shear | 0.042 MPa — 841×. The couple is carried in bearing, not in the bond |

### The skin is what survives over the SLOT, not over the tang — and that was a bug

Worth stating on its own, because it was a **failing joint reporting a pass.**
`skin_thickness` was `(panel - tang) / 2`. The slot is the tang plus a 0.1 mm bond line on
each face, so the real skin is `(panel - tang - 2·bond) / 2` — 0.5 mm where the model said
0.6. Skin stress goes as 1/t², so the joint was actually at **1.69× against a 2.0×
requirement** while reporting 2.5×. `RootJoint` now carries `bond_line`, and the skin spans
`slot_width`, not `tang_width`.

It surfaced only because a buyability question forced the stack to be expressed in sheet
thicknesses you can order. Asking "which sheets do I buy" is a different question from
"what dimensions are optimal", and it found something the second question could not.

### The panel is a laminate of two stocked sheets

**1.0 / 2.0 / 1.0 mm bonded G10, 4.0 mm total** (0.8/2.0/0.8 before correction 61 — the
skin over the slot fell to 1.93x at a horizontal launch's sea-level max q), the middle sheet cut away over
12.1 × 25.5 mm at the root. That gap **is** the slot — it never gets machined.

> **0.6 → 0.8 mm skins at the Sep 2026 freeze.** The panel went to 1.30 cal semispan, which
> puts 28.8 N through the root instead of 21.1 and moves the CP outboard, so bending at the
> wall doubled to 1.273 N·m. At 0.6 mm the skin spanning the slot worked at 327 MPa against
> a 480 MPa allowable — **1.47×**, under the 2.0× this project requires. 0.8 mm restores
> 2.65×. 0.8 mm is 1/32 in and is one of the most common G10 sheet thicknesses sold, so the
> "sum of stocked sheets" argument is unchanged. See `docs/00-requirements.md` §7.2.

The earlier spec, 0.6 / 1.8 / 0.6, is dead twice over: **1.8 mm G10 is not stocked
anywhere**, and it was the thickness that produced the 1.69× above. Every thickness in the
new stack is a sheet you can order. Check that before changing any of them.

This moved `canard_thickness` **3.0 → 3.2 mm**, which is a frozen parameter changed for a
manufacturing reason, so it is worth being explicit about what it did:

| | |
|---|---|
| canard flutter margin | 4.46× → **4.92×** — thicker t/c, so this improves |
| panel mass | +9 g, at station 0.507 m, which is **forward** of the 0.800 m CG |
| static margin | 2.03–2.52 → **2.04–2.53 cal** — up, because that mass is forward |
| crossrange | 424 → **419 m**, about 1%. This is the honest cost |
| `evaluate()` | still feasible, no violations |

**The alternative was a solid 3.0 mm plate with the slot cut by a slitting saw on a mill.**
It keeps the frozen thickness and needs no bonding, but it lands at 2.1× rather than 2.5×,
and its 0.55 mm skins depend on centring a slot in a 3.0 mm plate to ±0.05 mm — a *setup*
tolerance rather than a *stock* one. The laminate was chosen because a 3D printer makes its
one weakness — holding three layers and a tang in alignment while epoxy cures — into a
printed jig, and because a thickness guaranteed by the sheet beats one guaranteed by a
fixture.

### The depth was the expensive axis, not the free one

The first version of this section put the tang at **30 mm** and justified it like this:
*"depth is bought cheaply — slot pressure goes as 1/L², so it improves everything at once
and is paid for nowhere."* Both halves of that are true and it is still the wrong answer,
because it priced the tang against stress and the binding constraint is **geometry**.

**The panel is swept 35.4°.** Its leading edge runs aft **0.71 mm for every mm of span**,
while the tang stays in a fixed axial band about the hinge axis — it has to, being the end
of a shaft that turns about that axis. So every millimetre of depth spends better than half
a millimetre of leading-edge material:

| engagement | material ahead of the tang tip | |
|---|---|---|
| 25.5 mm | **+6.15 mm** | selected |
| 30.0 mm | +1.91 mm | previously selected, on strength alone |
| 32.7 mm | 0.00 mm | the tang reaches the leading edge |
| 40.5 mm | **−5.53 mm** | *what the old 60%-of-chord rule allowed* |

That last row is the point. The depth rule that was supposed to bound this **passed a tang
standing 5.18 mm proud of the panel's leading edge** — not a part with a thin margin, a part
that cannot be made. A rule that admits an unbuildable geometry is worse than no rule,
because it reads like a check.

Both failing cases are kept and exercised by `scripts/hinge_report.py`, which exits
non-zero if either passes: the ⌀6 sleeve butted into a 3 mm panel (fails on *there is no
panel left*), and the 1.8 × 14 × 30 tang — **whose every stress margin is better than the
selected joint's and which is still not buildable.** That is the only
case in this project that fails on geometry while passing on strength, which is exactly why
it is worth keeping.

### And a datum error under that, which only the CAD caught

The first fix set the tang at 26.5 mm and read **5.50 mm** of leading edge. The real number
was **5.14 mm**, and the difference is a datum:

- `engagement` is measured from the **panel root face**, R 40.200.
- The planform's sweep and semispan are measured from the **theoretical root** — the tube
  surface, R 39.700.

Those differ by the 0.500 mm assembly standoff, and feeding one into the other over-read
the clearance by 0.500 × 0.71. The analysis agreed with itself perfectly; it disagreed with
Onshape, where **panel 0 runs R 40.20 → 107.19, and 107.19 is 39.700 + 67.490, not
40.200 + 67.490.** Reading the real model is what surfaced it.

Everything on the joint is now indexed by **radius**, which is what `HingeStack`'s own
docstring already said to do — *"radius, not distance from the wall, because radius is the
coordinate every one of these parts is actually positioned in"* — and which `RootJoint` had
not been doing. `body_radius` is now a field, and `leading_edge()`, `chord()` and
`trailing_edge()` all take a radius.

The selected 25.0 mm delivers **6.71 mm**, so the joint is no longer sitting 0.14 mm above
its own requirement.

**A second bug fell out of writing the check.** `slot_chord_fraction` divided the engagement
by the **root chord**. The tang reaches along the **span**; the chord is what its *width*
lies along. It returned the right number anyway — `canard_root_cal` and
`canard_semispan_cal` are both 0.85, so both lengths are 67.490 mm — and would have
silently read the wrong dimension the moment either parameter moved. Same class of error as
the sketch that measured to a circle's tangent instead of its centre. Now
`slot_span_fraction`, and the panel planform is passed to `RootJoint` whole so the joint
cannot drift from the aerodynamics.

Two things to carry into the build, both of which fall out of the model rather than out of
anyone's judgement:

- **The round-to-flat transition steps the stress up 3.4×, at the maximum-moment station.**
  Blend it. Do not shoulder it.
- **THE PANEL STOPS BEING A PLATE.** A 1.8 mm slot 25.5 mm deep into the edge of a solid
  plate is a **13:1 blind cut**, which is not a thing you machine without a slitting saw. The panel is built as a
  **1.0 / 2.0 / 1.0 mm bonded G10 laminate, 4.0 mm** (correction 61) with the core cut away where the tang goes.
  Same planform and the same aerodynamics; the thickness goes 3.0 → 3.2 → 3.6 because a
  laminate can only be a sum of sheets that are sold, and that is priced in "The panel is a laminate
  of two stocked sheets" above. The real answer to "how does the shaft meet the panel"
  turned out to be "the panel is made differently."

The check is exercised against the obvious joint too — the ⌀6 sleeve simply entering the
panel — where it fails on *there is no panel left*. Same principle as `as_built`: a check
that has never failed is not evidence of anything.

Model in `design/hinge.py` (`RootJoint`, `root_joint_loads`, `check_root_joint`);
`scripts/hinge_report.py` prints it; `scripts/baseline.py` carries the verdict.

## The tube at the hinge station — four bores at one station

`check_hinge_stack()` has emitted *"the wall bore is ⌀7.97 mm in a 2.3 mm wall — check the
tube, not just the hinge"* since the hinge stack went in, and until August 2026 nothing had.
It is the same shape of gap the hinge stack itself was written for: **the bore was sized
against the bearing, and nobody asked what four of them do to the tube.**

Four ⌀7.975 bores at one station take **13.2% of the circumference** of a 79.4 × 2.3 tube —
557.1 mm² gross down to 483.7 mm² net, 52.6 mm of ligament between adjacent bores.

Loads, from three different flight conditions and deliberately **not** combined — the
vehicle is not doing all three at once, and the margins are wide enough that the question
does not arise:

| | |
|---|---|
| Axial | **143.6 N** at t = 2.47 s: 1.229 kg forward of the station at 7.24 g, plus 56 N of drag |
| Bending | **0.999 N·m** at max q, free body forward of the station **with inertial relief** |
| Torsion | **6.965 N·m** at a full roll command: four panels × 25.4 N at R 68.6 mm |

| margin | |
|---|---|
| **bearing seat crush** | **3.2×** |
| press-fit hoop | 29.9× |
| net section (compression + bending, Kt = 3.0) | 255.8× |
| torsional shear | 348.0× |
| shell buckling | 434.1× |

**The tube is fine, and it is not close** — by two to three orders of magnitude on every
margin except one. The interesting result is the exception.

**The bearing seat is the tightest thing at this station, and only because the housing
collar does not exist.** The bearing hands its couple to whatever holds it, and 3.700 mm of
its 6.0 mm sits inboard of the tube ID. With no collar, the 2.3 mm wall holds it alone:
**116.2 MPa, 3.2×**. With the collar, the full 6.0 mm carries it: **17.4 MPa, 21.3×**. The
peak pressure goes as 1/L², so the two answers are a factor of **6.7×** apart, and that gap
is the whole argument for building the collar. It is still blocked on bracket hardware
(step 6) — but it is now blocked on something with a number attached.

Two honest caveats, both stated in `design/materials.py` rather than buried:

- **The allowables are NEMA G-10 / FR-4 *sheet* properties, and a filament-wound airframe
  tube is not sheet.** A ±45° wind is stiffer in torsion and weaker in axial; a rolled or
  pultruded tube is different again. The project has only ever committed to one material
  fact, the 1850 kg/m³ density in `configure.py`. The convention adopted: **if a margin
  lands under 4×, stop and get the real tube datasheet.** The bearing seat at 3.2× is under
  that line, and the report says so.
- **Global airframe beam bending under a gust is not modelled** — here or anywhere in the
  project; this is the first structural model it has. The free body runs at the **trim**
  condition the trajectory actually flies, not at a certification gust case.
  `check_cut_station()` takes a `gust_factor` so a reviewer can scale it without editing
  the load path.

Model in `design/tube_section.py`, allowables in `design/materials.py`,
printed by `scripts/hinge_report.py`, verdict carried in `scripts/baseline.py`.

## How this actually gets built

Added August 2026, once it was established that parts get **bought** and the shop is a 3D
printer rather than a machine shop. Every dimension above is reachable that way, but only
in a particular order, and the order is the part that is easy to get wrong.

**One custom-machined part in the whole module.** The canard shaft: a **⌀10** 6061-T6 rod
(⌀6 originally, ⌀8 at correction 61),
32.2 mm long, with a 1.8 × 11.9 × 25.5 mm blade milled on one end. Everything else is
bought or printed. If that goes to a shop, it is one drawing and four identical parts.

**Do not cut the servo spline — cast it.** The shaft's inboard end carries a **⌀4.100 ×
3.20 mm plain drilled socket**, not a broached one. Fill it with anaerobic retaining
compound and push it onto the servo spline: the compound cures in the tooth valleys and
*becomes* the female spline. Fifteen keys, formed by the part they mate with.

An earlier revision of this file said to buy a ⌀4 mm 15T horn instead. **That does not
fit** — there is 0.515 mm between the servo's output face and the bearing, and outboard of
that everything passes down the journal; every female-spline part sold is ⌀7 or larger.
See docs/04 "The coupling" and docs/01 correction 21.

**Corrections 61 and 62 took the journal to ⌀10, which is the first time that argument has
had any slack in it, and it is NOT re-opened here.** A ⌀7 female-spline part would now pass
down a ⌀10 journal — but the 0.515 mm between the servo face and the bearing has not moved, and
that is the dimension the bought horn actually failed on. The cast socket stays. Anyone
revisiting this must check the axial gap, not the diameter.

Either way the reasoning that made broaching avoidable still holds: **the coupling carries
torque only**, 0.520 N·m at servo stall, because the bearing sits outboard of it and takes
every bit of the bending. Prime the bore — 6061 is passive and anaerobics need an activator
on it, while the steel spline cures on its own.

**Ream the bearing seat AFTER the printed bay is bonded in.** This is the one that will bite
if it is done in the obvious order. The bearing is 6.0 mm long, the tube wall is 2.3 mm of
it, and a collar on the printed bay carries the other **3.700 mm**. Those two bores must be
concentric — if they are not, the bearing is pinched and the hinge binds, which is a
mechanism failure rather than a stress one and no margin in this document protects against
it. So:

1. Print the bay with the collar bore **undersize**, ⌀11.5 (⌀7.5 originally). FDM holes come out
   undersize and rough anyway; do not fight it.
2. Bond the bay into the tube.
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

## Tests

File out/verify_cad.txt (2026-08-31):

  quantity                       design          CAD      delta         
  bearing volume, mm^3          130.246      130.246     +0.000   +0.00%  ok
  shaft volume, mm^3            698.138      698.138     +0.000   +0.00%  ok
  bay volume, mm^3            28889.045    28256.421   -632.624   -2.19%  ok
  one retainer, mm^3            102.630       90.808    -11.822  -11.52%  ok
  aft gas seal, mm^3          20744.087    20744.087     -0.000   -0.00%  ok
  internal bulkhead, mm^3     20729.007    20729.007     +0.000   +0.00%  ok
  module mass, g                298.756      298.756     -0.000   -0.00%  ok
  module station, mm             75.151       75.151     +0.000   +0.00%  ok
  module I_transverse, e-6      622.187      622.187     +0.000   +0.00%  ok
  module I_roll, e-6            673.225      673.225     -0.000   -0.00%  ok

  assembly instances                  35  (want 35) ok
  assembly features                    9  (want 9) ok
  hand-placed revolute mates           4  (want 4) ok
  instances with no part reference     0  ok
  features not OK                      0  ok

  collar boss rim R 35.856 against a tube bored to R 37.400 -- checked on RADIUS, which is the thing an axis-aligned
  bounding box cannot tell you.

  ALL CONSISTENT

  This does NOT prove there are no interferences -- an interference moves no
  volume and no mass. Run 'Check interference...' in the browser for that.

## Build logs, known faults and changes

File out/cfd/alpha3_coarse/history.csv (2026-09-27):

Time_Iter | Outer_Iter | Inner_Iter | "rms[Rho]" | "rms[RhoU]" | "rms[RhoV]" | "rms[RhoW]" | "rms[RhoE]" | "RefForce" | "CD" | "CL" | "CSF" | "CMx" | "CMy" | "CMz" | "CFx" | "CFy" | "CFz" | "CEff" | "CD(BODY)" | "CD(CANARD0)" | "CD(CANARD1)" | "CD(CANARD2)" | "CD(CANARD3)" | "CD(FIN0)" | "CD(FIN1)" | "CD(FIN2)" | "CD(FIN3)" | "CL(BODY)" | "CL(CANARD0)" | "CL(CANARD1)" | "CL(CANARD2)" | "CL(CANARD3)" | "CL(FIN0)" | "CL(FIN1)" | "CL(FIN2)" | "CL(FIN3)" | "CSF(BODY)" | "CSF(CANARD0)" | "CSF(CANARD1)" | "CSF(CANARD2)" | "CSF(CANARD3)" | "CSF(FIN0)" | "CSF(FIN1)" | "CSF(FIN2)" | "CSF(FIN3)" | "CMx(BODY)" | "CMx(CANARD0)" | "CMx(CANARD1)" | "CMx(CANARD2)" | "CMx(CANARD3)" | "CMx(FIN0)" | "CMx(FIN1)" | "CMx(FIN2)" | "CMx(FIN3)" | "CMy(BODY)" | "CMy(CANARD0)" | "CMy(CANARD1)" | "CMy(CANARD2)" | "CMy(CANARD3)"
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

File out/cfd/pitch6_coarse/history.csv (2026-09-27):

Time_Iter | Outer_Iter | Inner_Iter | "rms[Rho]" | "rms[RhoU]" | "rms[RhoV]" | "rms[RhoW]" | "rms[RhoE]" | "RefForce" | "CD" | "CL" | "CSF" | "CMx" | "CMy" | "CMz" | "CFx" | "CFy" | "CFz" | "CEff" | "CD(BODY)" | "CD(CANARD0)" | "CD(CANARD1)" | "CD(CANARD2)" | "CD(CANARD3)" | "CD(FIN0)" | "CD(FIN1)" | "CD(FIN2)" | "CD(FIN3)" | "CL(BODY)" | "CL(CANARD0)" | "CL(CANARD1)" | "CL(CANARD2)" | "CL(CANARD3)" | "CL(FIN0)" | "CL(FIN1)" | "CL(FIN2)" | "CL(FIN3)" | "CSF(BODY)" | "CSF(CANARD0)" | "CSF(CANARD1)" | "CSF(CANARD2)" | "CSF(CANARD3)" | "CSF(FIN0)" | "CSF(FIN1)" | "CSF(FIN2)" | "CSF(FIN3)" | "CMx(BODY)" | "CMx(CANARD0)" | "CMx(CANARD1)" | "CMx(CANARD2)" | "CMx(CANARD3)" | "CMx(FIN0)" | "CMx(FIN1)" | "CMx(FIN2)" | "CMx(FIN3)" | "CMy(BODY)" | "CMy(CANARD0)" | "CMy(CANARD1)" | "CMy(CANARD2)" | "CMy(CANARD3)"
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

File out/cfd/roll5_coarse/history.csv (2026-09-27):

Time_Iter | Outer_Iter | Inner_Iter | "rms[Rho]" | "rms[RhoU]" | "rms[RhoV]" | "rms[RhoW]" | "rms[RhoE]" | "RefForce" | "CD" | "CL" | "CSF" | "CMx" | "CMy" | "CMz" | "CFx" | "CFy" | "CFz" | "CEff" | "CD(BODY)" | "CD(CANARD0)" | "CD(CANARD1)" | "CD(CANARD2)" | "CD(CANARD3)" | "CD(FIN0)" | "CD(FIN1)" | "CD(FIN2)" | "CD(FIN3)" | "CL(BODY)" | "CL(CANARD0)" | "CL(CANARD1)" | "CL(CANARD2)" | "CL(CANARD3)" | "CL(FIN0)" | "CL(FIN1)" | "CL(FIN2)" | "CL(FIN3)" | "CSF(BODY)" | "CSF(CANARD0)" | "CSF(CANARD1)" | "CSF(CANARD2)" | "CSF(CANARD3)" | "CSF(FIN0)" | "CSF(FIN1)" | "CSF(FIN2)" | "CSF(FIN3)" | "CMx(BODY)" | "CMx(CANARD0)" | "CMx(CANARD1)" | "CMx(CANARD2)" | "CMx(CANARD3)" | "CMx(FIN0)" | "CMx(FIN1)" | "CMx(FIN2)" | "CMx(FIN3)" | "CMy(BODY)" | "CMy(CANARD0)" | "CMy(CANARD1)" | "CMy(CANARD2)" | "CMy(CANARD3)"
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

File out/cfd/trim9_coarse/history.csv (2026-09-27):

Time_Iter | Outer_Iter | Inner_Iter | "rms[Rho]" | "rms[RhoU]" | "rms[RhoV]" | "rms[RhoW]" | "rms[RhoE]" | "RefForce" | "CD" | "CL" | "CSF" | "CMx" | "CMy" | "CMz" | "CFx" | "CFy" | "CFz" | "CEff" | "CD(BODY)" | "CD(CANARD0)" | "CD(CANARD1)" | "CD(CANARD2)" | "CD(CANARD3)" | "CD(FIN0)" | "CD(FIN1)" | "CD(FIN2)" | "CD(FIN3)" | "CL(BODY)" | "CL(CANARD0)" | "CL(CANARD1)" | "CL(CANARD2)" | "CL(CANARD3)" | "CL(FIN0)" | "CL(FIN1)" | "CL(FIN2)" | "CL(FIN3)" | "CSF(BODY)" | "CSF(CANARD0)" | "CSF(CANARD1)" | "CSF(CANARD2)" | "CSF(CANARD3)" | "CSF(FIN0)" | "CSF(FIN1)" | "CSF(FIN2)" | "CSF(FIN3)" | "CMx(BODY)" | "CMx(CANARD0)" | "CMx(CANARD1)" | "CMx(CANARD2)" | "CMx(CANARD3)" | "CMx(FIN0)" | "CMx(FIN1)" | "CMx(FIN2)" | "CMx(FIN3)" | "CMy(BODY)" | "CMy(CANARD0)" | "CMy(CANARD1)" | "CMy(CANARD2)" | "CMy(CANARD3)"
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

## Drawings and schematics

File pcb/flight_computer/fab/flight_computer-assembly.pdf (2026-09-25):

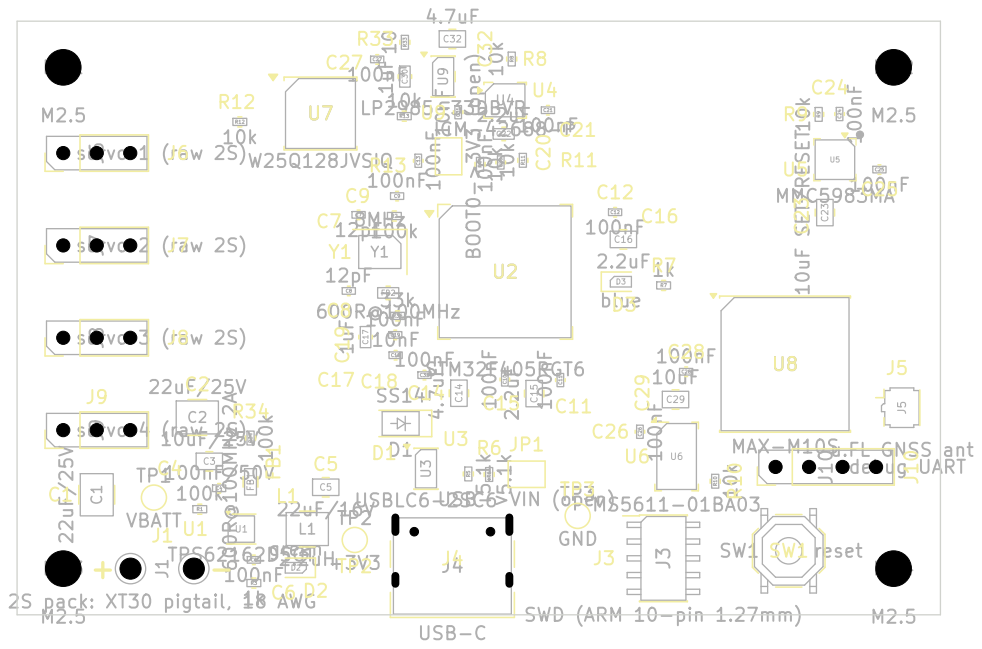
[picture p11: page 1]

Size: A3 | Rev: | F Date:
KiCad E.D.A. 10.0.6 | Id: 1/1

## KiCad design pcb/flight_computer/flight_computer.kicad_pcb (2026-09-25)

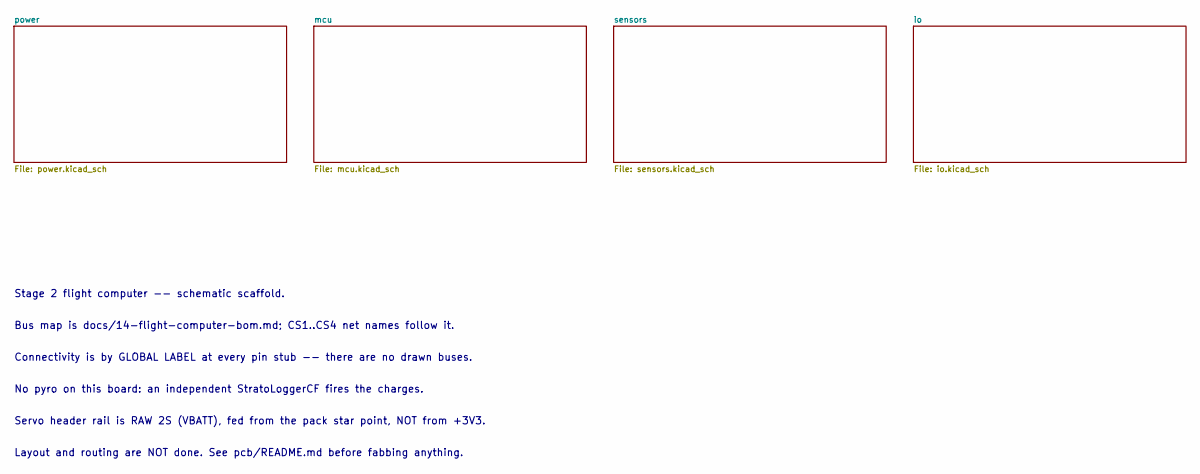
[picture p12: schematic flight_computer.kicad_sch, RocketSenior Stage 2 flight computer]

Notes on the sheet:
Stage 2 flight computer -- schematic scaffold.
Bus map is docs/14-flight-computer-bom.md; CS1..CS4 net names follow it.
Connectivity is by GLOBAL LABEL at every pin stub -- there are no drawn buses.
No pyro on this board: an independent StratoLoggerCF fires the charges.
Servo header rail is RAW 2S (VBATT), fed from the pack star point, NOT from +3V3.
Layout and routing are NOT done. See pcb/README.md before fabbing anything.

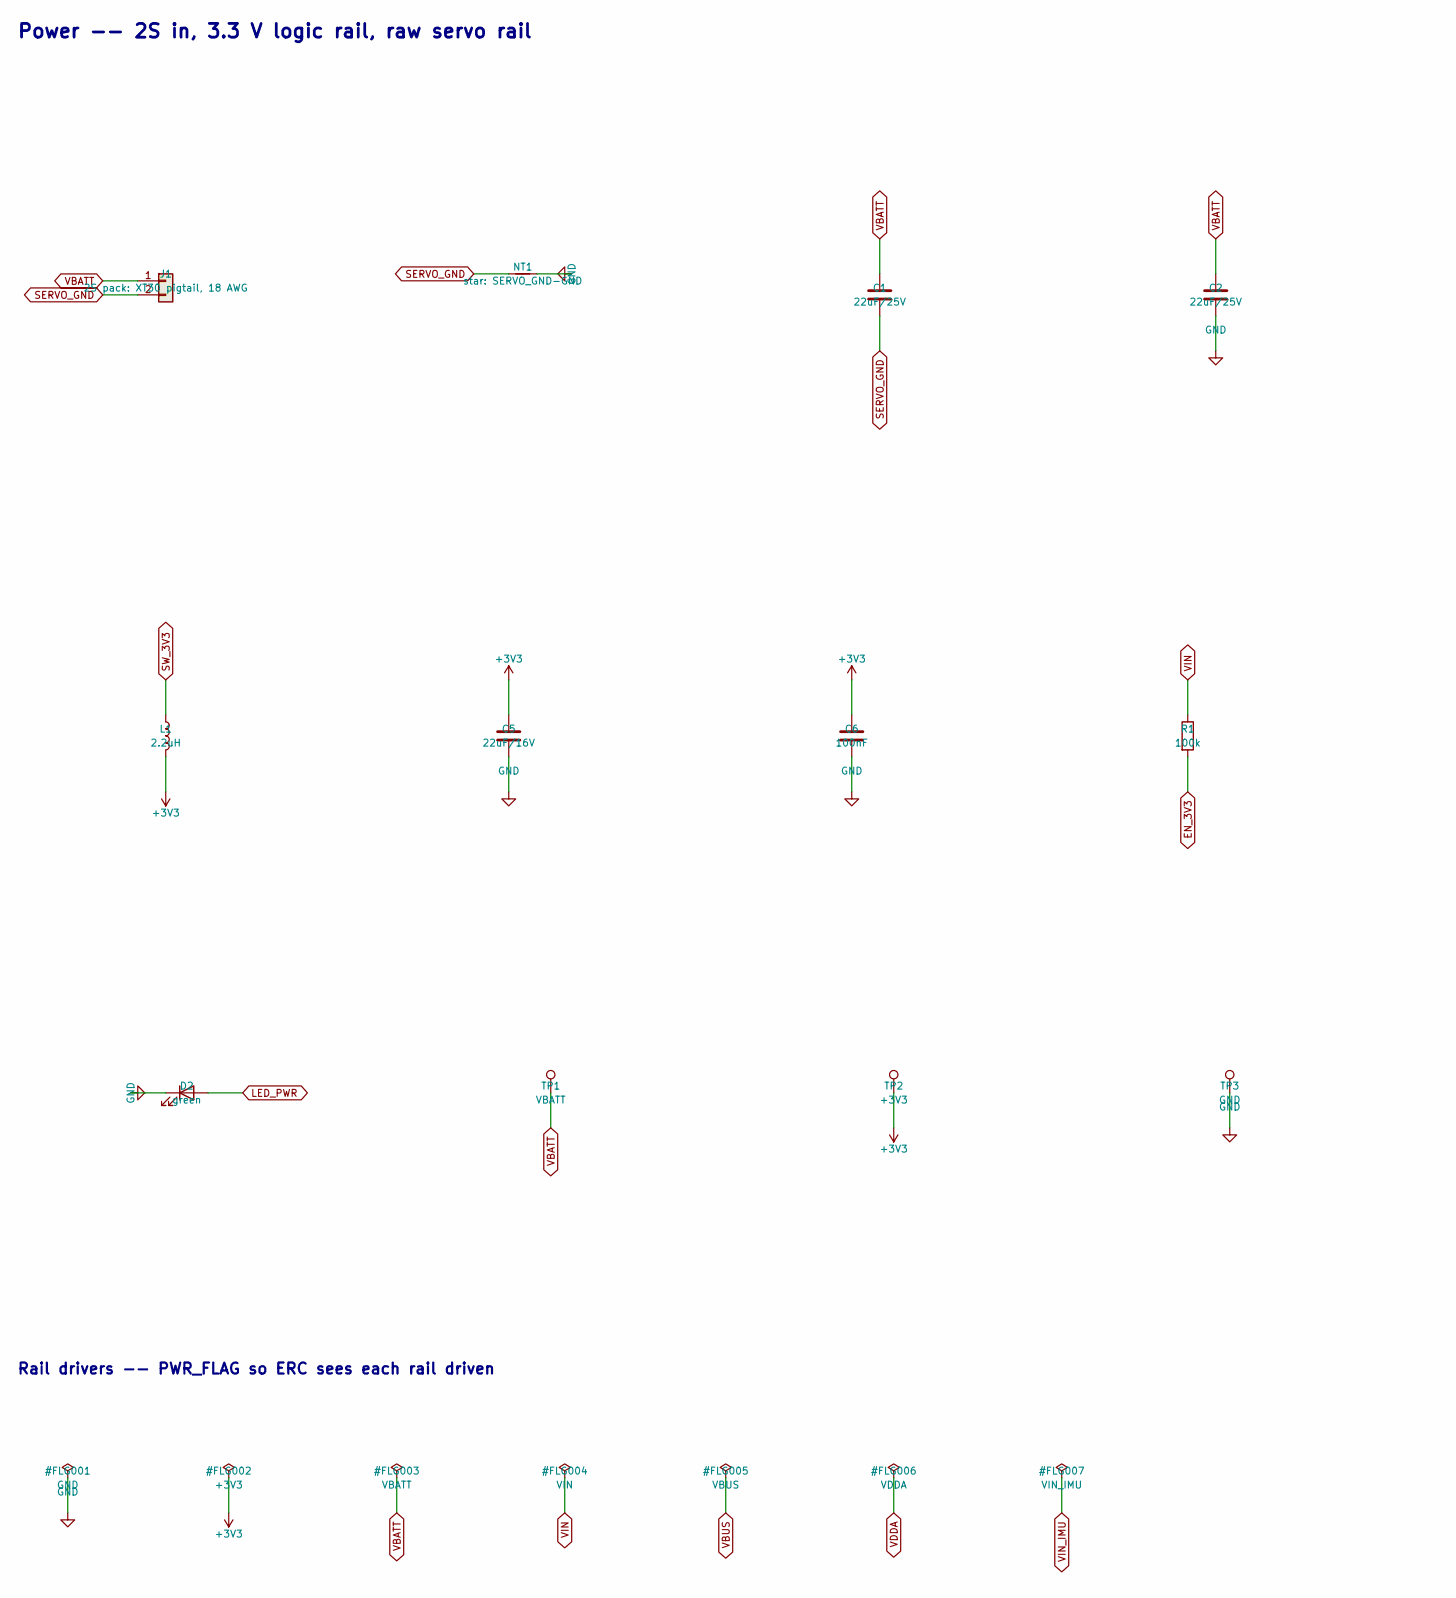
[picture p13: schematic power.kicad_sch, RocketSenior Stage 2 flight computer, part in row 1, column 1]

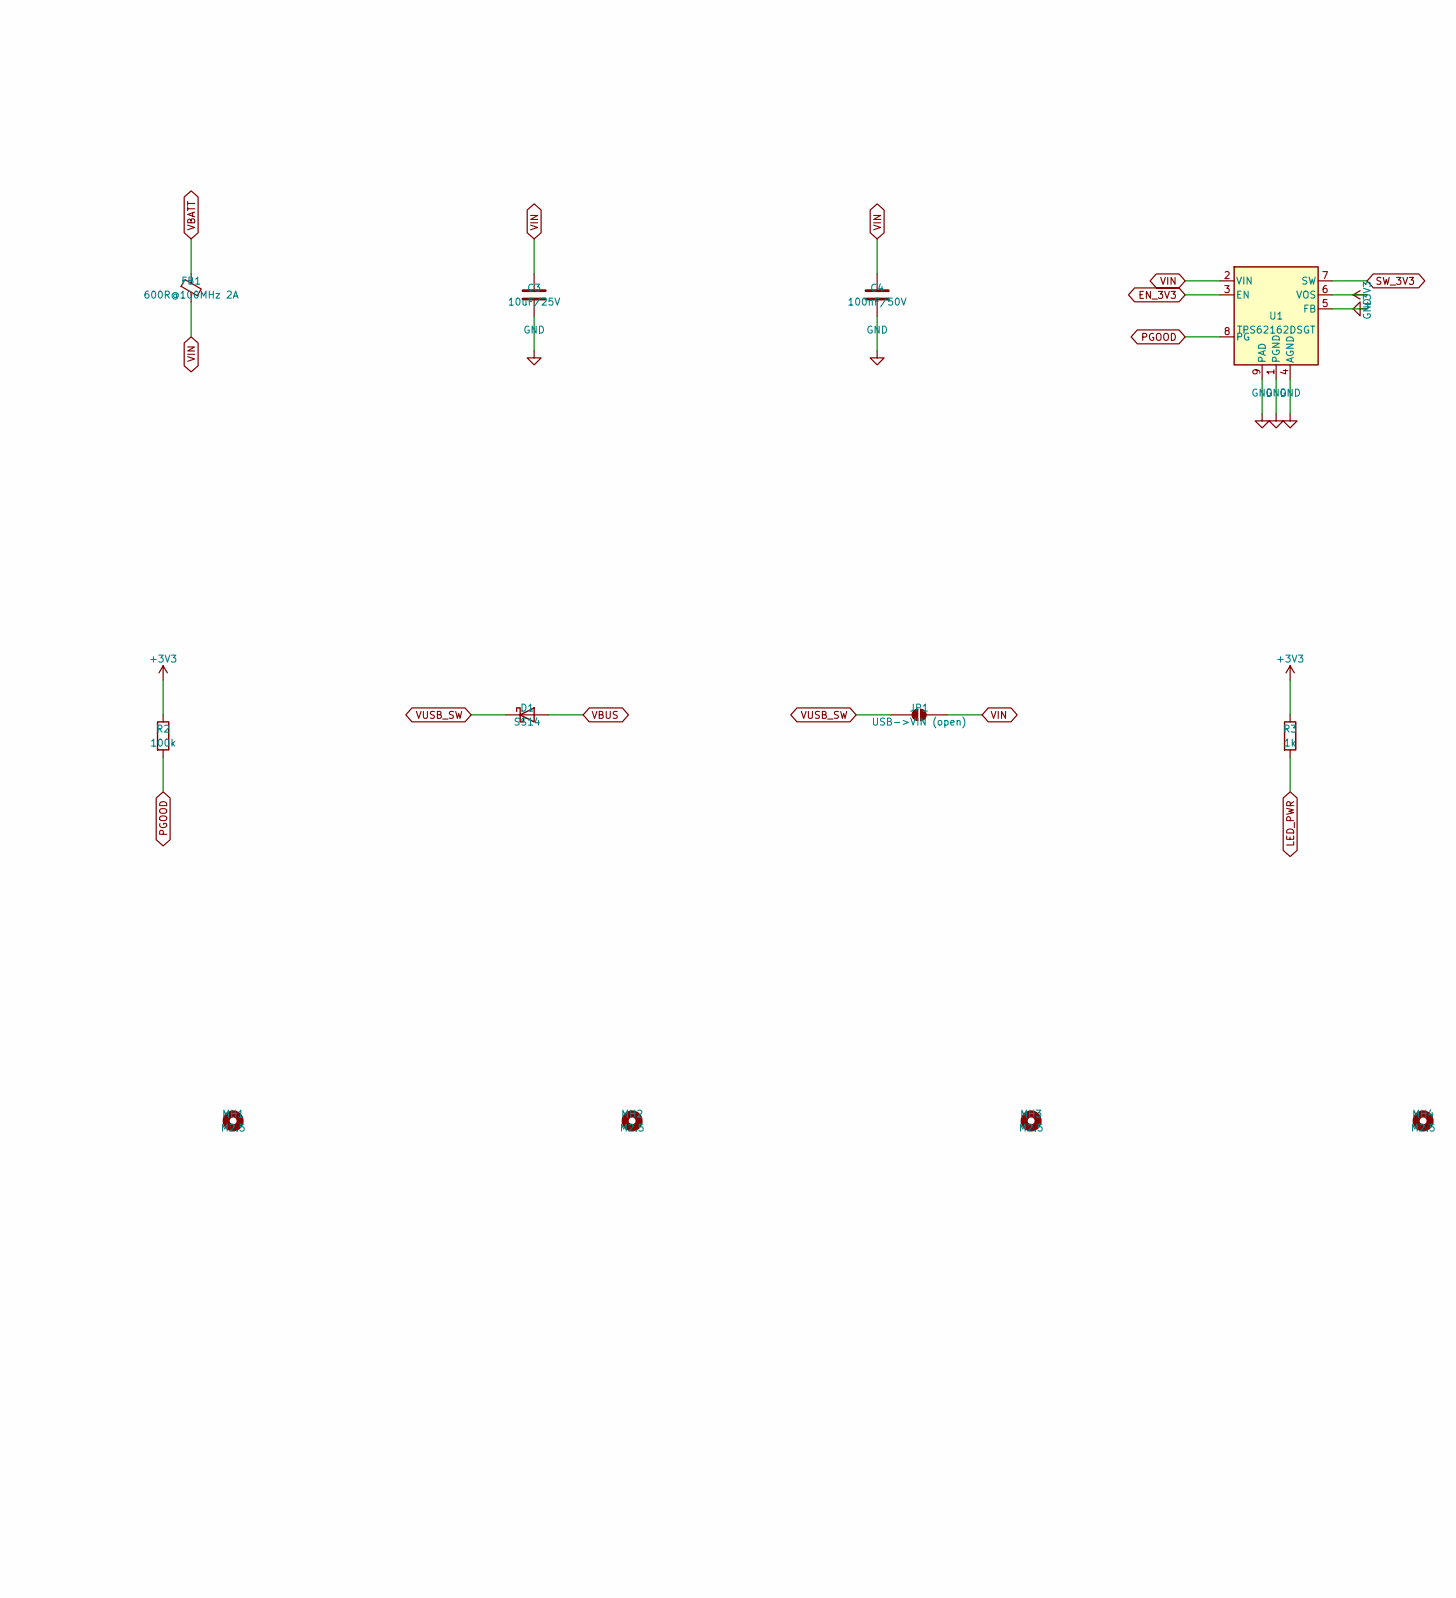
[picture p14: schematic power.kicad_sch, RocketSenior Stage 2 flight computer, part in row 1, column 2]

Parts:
C1, C2: 22uF/25V; C_1210_3225Metric
C3: 10uF/25V; C_0805_2012Metric
C4: 100nF/50V; C_0402_1005Metric
C5: 22uF/16V; C_0805_2012Metric
C6: 100nF; C_0402_1005Metric
D1: SS14; D_SOD-123
D2: green; LED_0603_1608Metric
FB1: 600R@100MHz 2A; L_0805_2012Metric
J1: 2S pack: XT30 pigtail, 18 AWG; SolderWire-0.75sqmm_1x02_P4.8mm_D1.25mm_OD2.3mm
JP1: USB->VIN (open); SolderJumper-2_P1.3mm_Open_Pad1.0x1.5mm
L1: 2.2uH; L_1210_3225Metric
MH1, MH2, MH3, MH4: M2.5; MountingHole_2.7mm_M2.5
NT1: star: SERVO_GND-GND; NetTie-2_SMD_Pad0.5mm
R1, R2: 100k; R_0402_1005Metric
R3: 1k; R_0402_1005Metric
TP1: VBATT; TestPoint_Pad_D1.5mm
TP2: +3V3; TestPoint_Pad_D1.5mm
TP3: GND; TestPoint_Pad_D1.5mm
U1: TPS62162DSGT; Texas_DSG0008A_WSON-8-1EP_2x2mm_P0.5mm_EP0.9x1.6mm

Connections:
+3V3: C5.1, C6.1, L1.2, R2.1, R3.1, TP2.1, U1.6 (VOS); also elsewhere on the board
EN_3V3: R1.2, U1.3 (EN)
GND: C2.2, C3.2, C4.2, C5.2, C6.2, D2.1 (K), NT1.2, TP3.1, U1.1 (PGND), U1.4 (AGND), U1.5 (FB), U1.9 (PAD); also elsewhere on the board
LED_PWR: D2.2 (A), R3.2
PGOOD: R2.2, U1.8 (PG); also elsewhere on the board
SERVO_GND: C1.2, J1.2, NT1.1; also elsewhere on the board
SW_3V3: L1.1, U1.7 (SW)
VBATT: C1.1, C2.1, FB1.1, J1.1, TP1.1; also elsewhere on the board
VBUS: D1.2 (A); also elsewhere on the board
VIN: C3.1, C4.1, FB1.2, JP1.2 (B), R1.1, U1.2 (VIN); also elsewhere on the board
VUSB_SW: D1.1 (K), JP1.1 (A)

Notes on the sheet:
Power -- 2S in, 3.3 V logic rail, raw servo rail
Rail drivers -- PWR_FLAG so ERC sees each rail driven

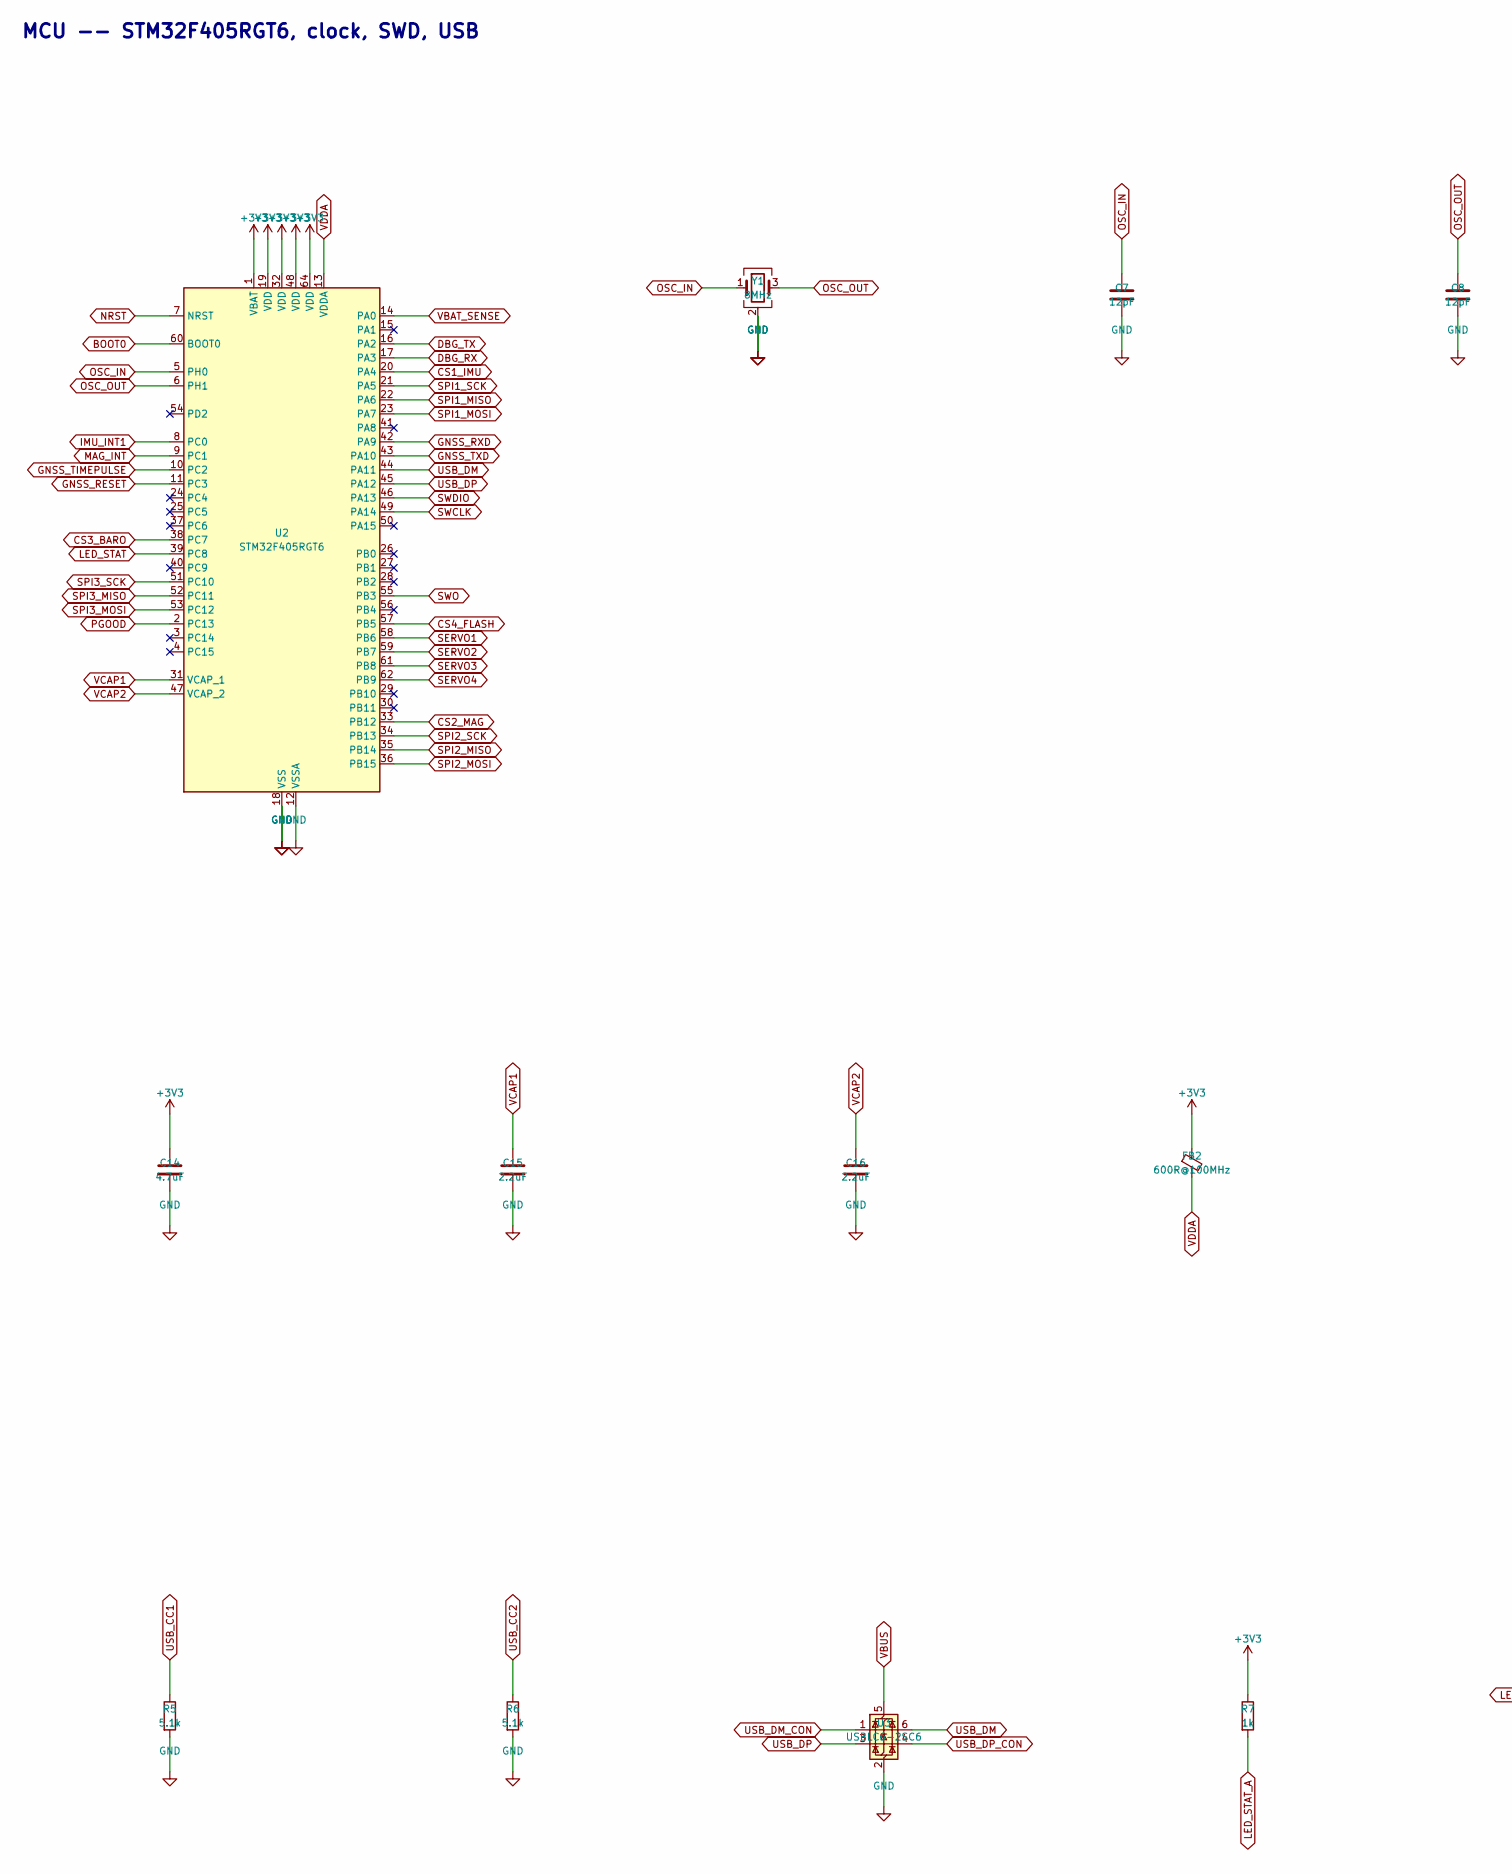
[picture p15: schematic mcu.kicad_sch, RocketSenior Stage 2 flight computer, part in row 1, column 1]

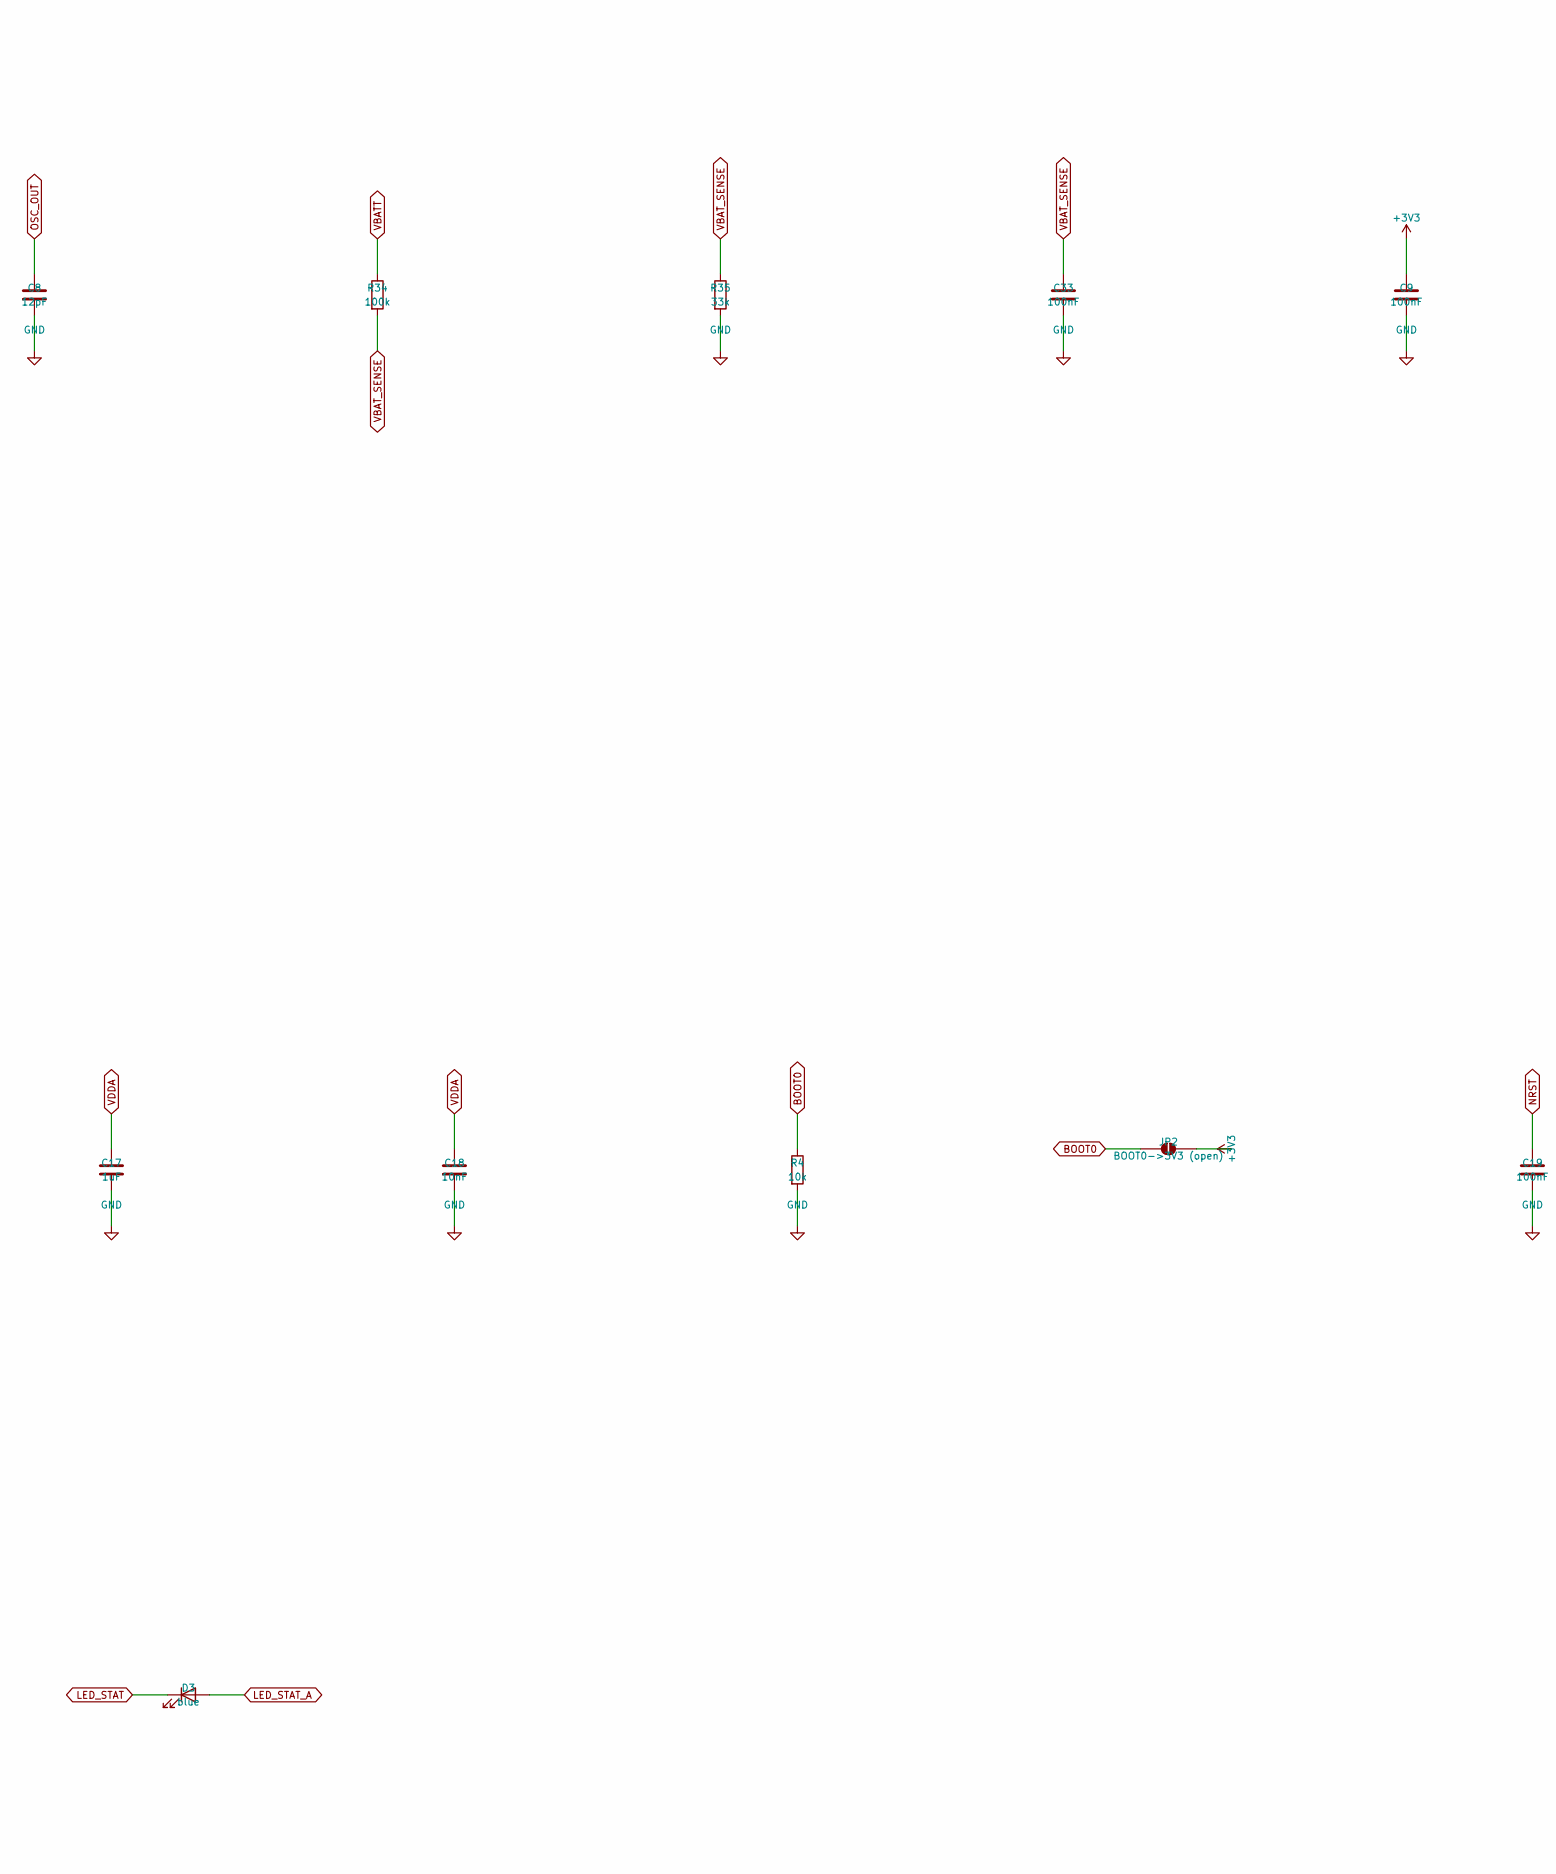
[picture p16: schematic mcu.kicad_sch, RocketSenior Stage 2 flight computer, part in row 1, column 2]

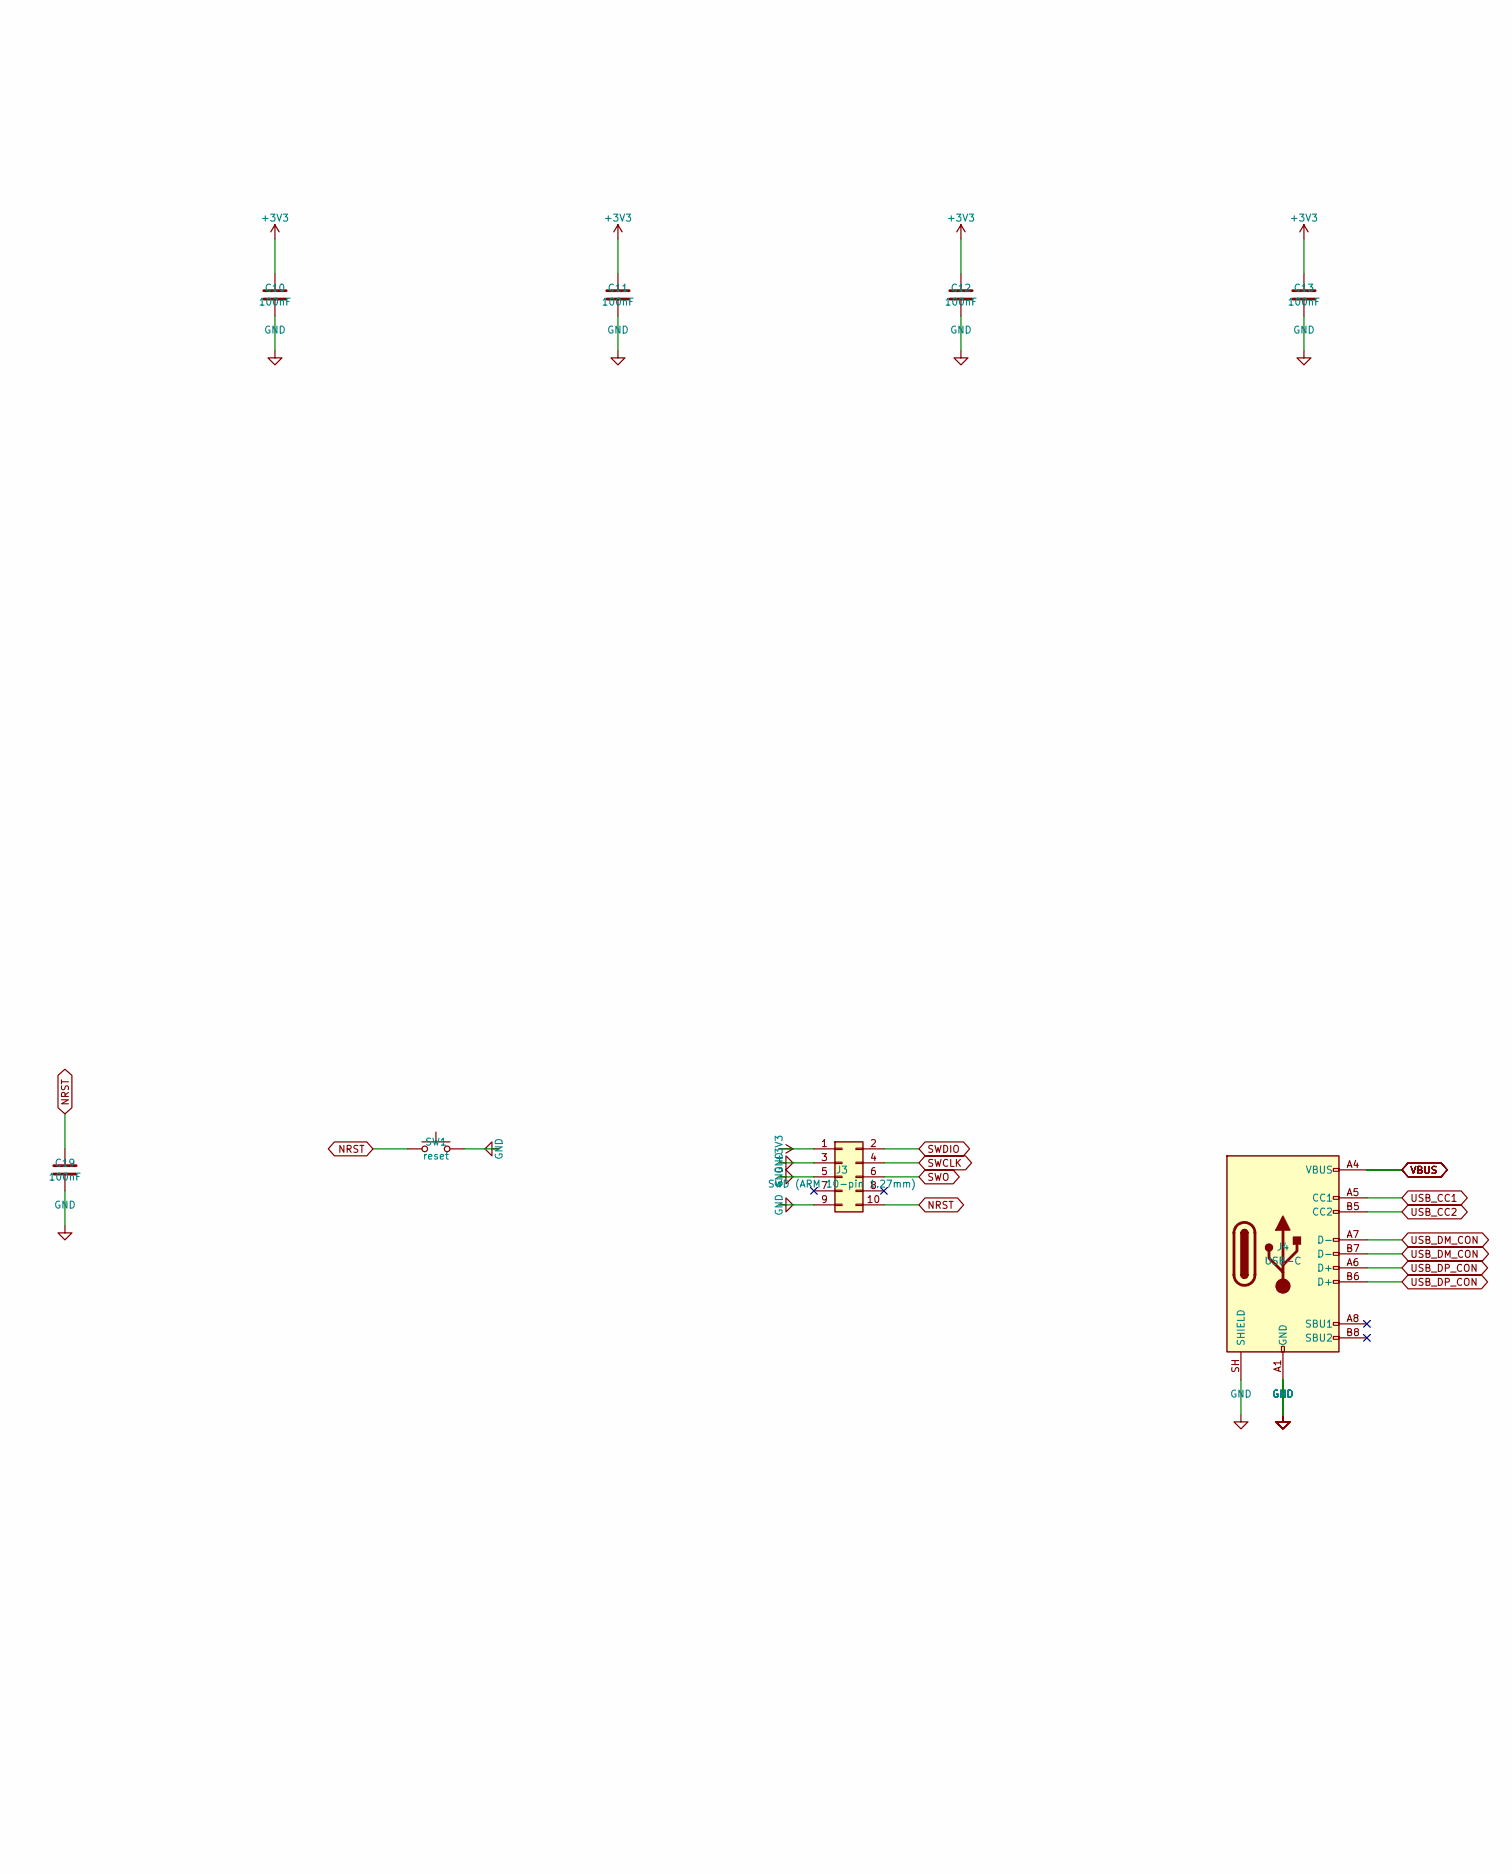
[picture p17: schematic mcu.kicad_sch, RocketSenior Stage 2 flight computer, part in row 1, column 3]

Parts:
C7, C8: 12pF; C_0402_1005Metric
C9, C10, C11, C12, C13, C19, C33: 100nF; C_0402_1005Metric
C14: 4.7uF; C_0805_2012Metric
C15, C16: 2.2uF; C_0805_2012Metric
C17: 1uF; C_0603_1608Metric
C18: 10nF; C_0402_1005Metric
D3: blue; LED_0603_1608Metric
FB2: 600R@100MHz; L_0603_1608Metric
J3: SWD (ARM 10-pin 1.27mm); PinHeader_2x05_P1.27mm_Vertical_SMD
J4: USB-C; USB_C_Receptacle_HRO_TYPE-C-31-M-12
JP2: BOOT0->3V3 (open); SolderJumper-2_P1.3mm_Open_Pad1.0x1.5mm
R4: 10k; R_0402_1005Metric
R5, R6: 5.1k; R_0402_1005Metric
R7: 1k; R_0402_1005Metric
R34: 100k; R_0402_1005Metric
R35: 33k; R_0402_1005Metric
SW1: reset; SW_SPST_TL3342
U2: STM32F405RGT6; LQFP-64_10x10mm_P0.5mm
U3: USBLC6-2SC6; SOT-23-6
Y1: 8MHz; Crystal_SMD_3225-4Pin_3.2x2.5mm

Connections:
+3V3: C9.1, C10.1, C11.1, C12.1, C13.1, C14.1, FB2.1, J3.1, JP2.2 (B), R7.1, U2.1 (VBAT), U2.19 (VDD), U2.32 (VDD), U2.48 (VDD), U2.64 (VDD); also elsewhere on the board
BOOT0: JP2.1 (A), R4.1, U2.60 (BOOT0)
CS1_IMU: U2.20 (PA4); also elsewhere on the board
CS2_MAG: U2.33 (PB12); also elsewhere on the board
CS3_BARO: U2.38 (PC7); also elsewhere on the board
CS4_FLASH: U2.57 (PB5); also elsewhere on the board
DBG_RX: U2.17 (PA3); also elsewhere on the board
DBG_TX: U2.16 (PA2); also elsewhere on the board
GND: C7.2, C8.2, C9.2, C10.2, C11.2, C12.2, C13.2, C14.2, C15.2, C16.2, C17.2, C18.2, C19.2, C33.2, J3.3, J3.5, J3.9, J4.A1 (GND), J4.A12 (GND), J4.B1 (GND), J4.B12 (GND), J4.SH (SHIELD), R4.2, R5.2, R6.2, R35.2, SW1.2, U2.12 (VSSA), U2.18 (VSS), U2.63 (VSS), U3.2 (GND), Y1.2 (G), Y1.4 (G); also elsewhere on the board
GNSS_RESET: U2.11 (PC3); also elsewhere on the board
GNSS_RXD: U2.42 (PA9); also elsewhere on the board
GNSS_TIMEPULSE: U2.10 (PC2); also elsewhere on the board
GNSS_TXD: U2.43 (PA10); also elsewhere on the board
IMU_INT1: U2.8 (PC0); also elsewhere on the board
LED_STAT: D3.1 (K), U2.39 (PC8)
LED_STAT_A: D3.2 (A), R7.2
MAG_INT: U2.9 (PC1); also elsewhere on the board
NRST: C19.1, J3.10, SW1.1, U2.7 (NRST)
OSC_IN: C7.1, U2.5 (PH0), Y1.1
OSC_OUT: C8.1, U2.6 (PH1), Y1.3
PGOOD: U2.2 (PC13); also elsewhere on the board
SERVO1: U2.58 (PB6); also elsewhere on the board
SERVO2: U2.59 (PB7); also elsewhere on the board
SERVO3: U2.61 (PB8); also elsewhere on the board
SERVO4: U2.62 (PB9); also elsewhere on the board
SPI1_MISO: U2.22 (PA6); also elsewhere on the board
SPI1_MOSI: U2.23 (PA7); also elsewhere on the board
SPI1_SCK: U2.21 (PA5); also elsewhere on the board
SPI2_MISO: U2.35 (PB14); also elsewhere on the board
SPI2_MOSI: U2.36 (PB15); also elsewhere on the board
SPI2_SCK: U2.34 (PB13); also elsewhere on the board
SPI3_MISO: U2.52 (PC11); also elsewhere on the board
SPI3_MOSI: U2.53 (PC12); also elsewhere on the board
SPI3_SCK: U2.51 (PC10); also elsewhere on the board
SWCLK: J3.4, U2.49 (PA14)
SWDIO: J3.2, U2.46 (PA13)
SWO: J3.6, U2.55 (PB3)
USB_CC1: J4.A5 (CC1), R5.1
USB_CC2: J4.B5 (CC2), R6.1
USB_DM: U2.44 (PA11), U3.6 (I/O1)
USB_DM_CON: J4.A7 (D-), J4.B7 (D-), U3.1 (I/O1)
USB_DP: U2.45 (PA12), U3.3 (I/O2)
USB_DP_CON: J4.A6 (D+), J4.B6 (D+), U3.4 (I/O2)
VBATT: R34.1; also elsewhere on the board
VBAT_SENSE: C33.1, R34.2, R35.1, U2.14 (PA0)
VBUS: J4.A4 (VBUS), J4.A9 (VBUS), J4.B4 (VBUS), J4.B9 (VBUS), U3.5 (VBUS); also elsewhere on the board
VCAP1: C15.1, U2.31 (VCAP_1)
VCAP2: C16.1, U2.47 (VCAP_2)
VDDA: C17.1, C18.1, FB2.2, U2.13 (VDDA)

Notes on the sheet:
MCU -- STM32F405RGT6, clock, SWD, USB

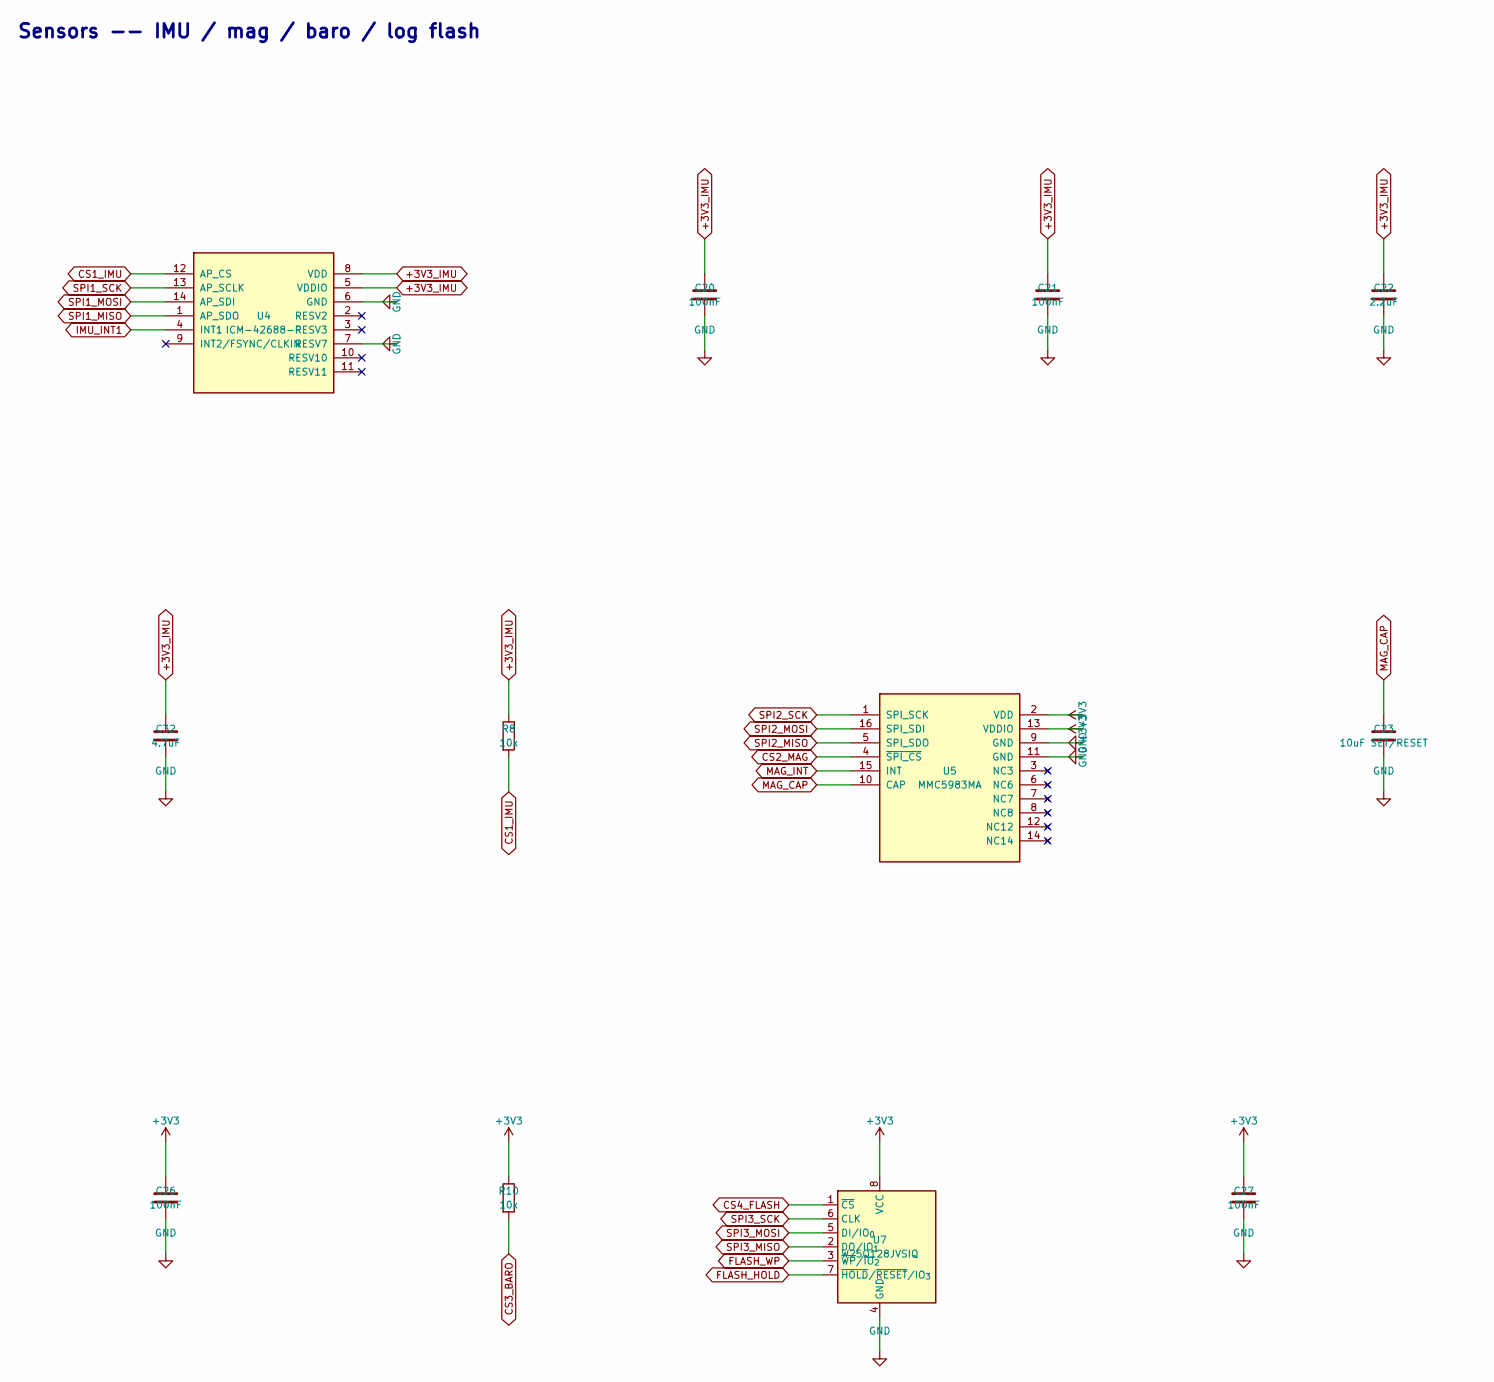
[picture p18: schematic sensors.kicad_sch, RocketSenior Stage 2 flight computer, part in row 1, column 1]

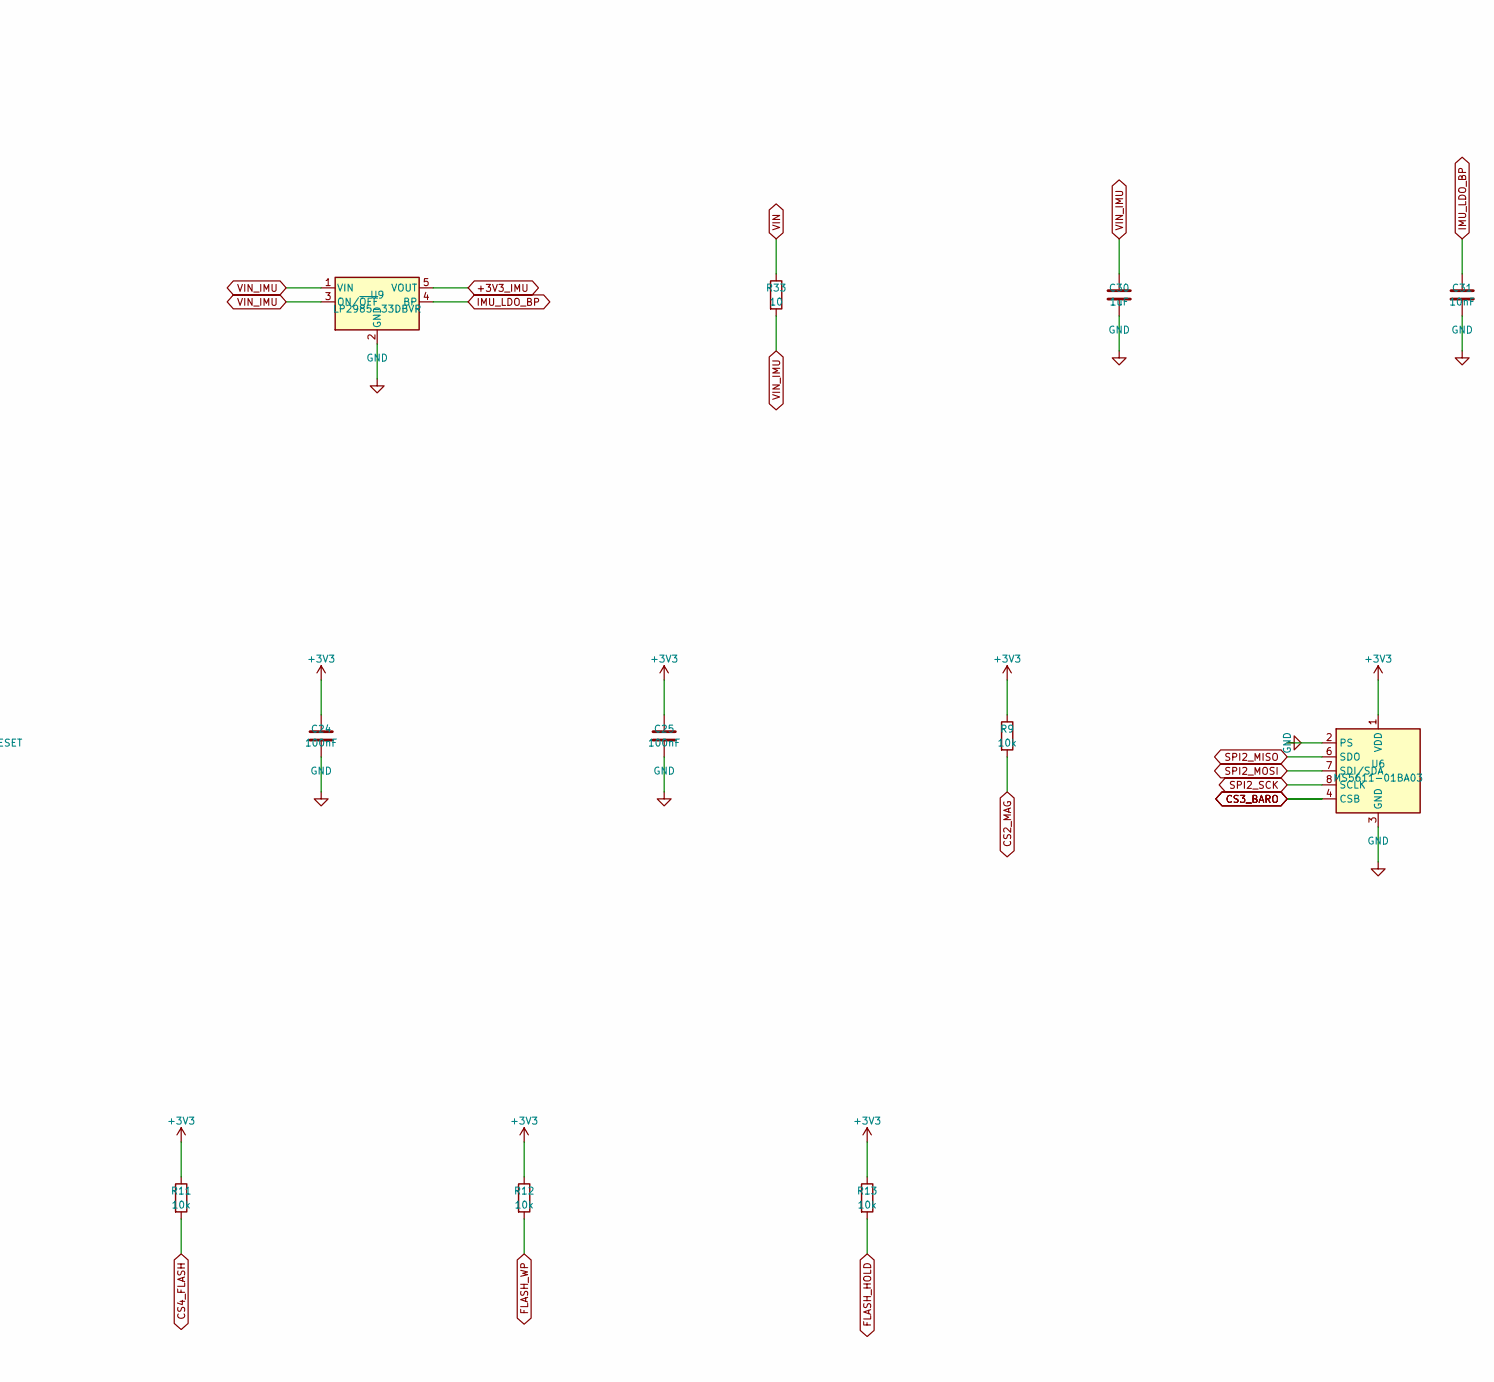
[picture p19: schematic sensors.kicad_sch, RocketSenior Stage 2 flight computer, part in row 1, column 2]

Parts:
C20, C21, C24, C25, C26, C27: 100nF; C_0402_1005Metric
C22: 2.2uF; C_0603_1608Metric
C23: 10uF SET/RESET; C_0805_2012Metric
C30: 1uF; C_0603_1608Metric
C31: 10nF; C_0402_1005Metric
C32: 4.7uF; C_0805_2012Metric
R8, R9, R10, R11, R12, R13: 10k; R_0402_1005Metric
R33: 10; R_0402_1005Metric
U4: ICM-42688-P; LGA-14_3x2.5mm_P0.5mm_LayoutBorder3x4y
U5: MMC5983MA; MMC5983MA_LGA-16_3x3mm_P0.5mm
U6: MS5611-01BA03; LGA-8_3x5mm_P1.25mm
U7: W25Q128JVSIQ; SOIC-8_5.3x5.3mm_P1.27mm
U9: LP2985-33DBVR; SOT-23-5

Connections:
+3V3: C24.1, C25.1, C26.1, C27.1, R9.1, R10.1, R11.1, R12.1, R13.1, U5.2 (VDD), U5.13 (VDDIO), U6.1 (VDD), U7.8 (VCC); also elsewhere on the board
+3V3_IMU: C20.1, C21.1, C22.1, C32.1, R8.1, U4.5 (VDDIO), U4.8 (VDD), U9.5 (VOUT)
CS1_IMU: R8.2, U4.12 (AP_CS); also elsewhere on the board
CS2_MAG: R9.2, U5.4 (~SPI_CS); also elsewhere on the board
CS3_BARO: R10.2, U6.4 (CSB), U6.5 (CSB); also elsewhere on the board
CS4_FLASH: R11.2, U7.1 (~CS); also elsewhere on the board
FLASH_HOLD: R13.2, U7.7 (~HOLD/~RESET/IO_{3})
FLASH_WP: R12.2, U7.3 (~WP/IO_{2})
GND: C20.2, C21.2, C22.2, C23.2, C24.2, C25.2, C26.2, C27.2, C30.2, C31.2, C32.2, U4.6 (GND), U4.7 (RESV7), U5.9 (GND), U5.11 (GND), U6.2 (PS), U6.3 (GND), U7.4 (GND), U9.2 (GND); also elsewhere on the board
IMU_INT1: U4.4 (INT1); also elsewhere on the board
IMU_LDO_BP: C31.1, U9.4 (BP)
MAG_CAP: C23.1, U5.10 (CAP)
MAG_INT: U5.15 (INT); also elsewhere on the board
SPI1_MISO: U4.1 (AP_SDO); also elsewhere on the board
SPI1_MOSI: U4.14 (AP_SDI); also elsewhere on the board
SPI1_SCK: U4.13 (AP_SCLK); also elsewhere on the board
SPI2_MISO: U5.5 (SPI_SDO), U6.6 (SDO); also elsewhere on the board
SPI2_MOSI: U5.16 (SPI_SDI), U6.7 (SDI/SDA); also elsewhere on the board
SPI2_SCK: U5.1 (SPI_SCK), U6.8 (SCLK); also elsewhere on the board
SPI3_MISO: U7.2 (DO/IO_{1}); also elsewhere on the board
SPI3_MOSI: U7.5 (DI/IO_{0}); also elsewhere on the board
SPI3_SCK: U7.6 (CLK); also elsewhere on the board
VIN: R33.1; also elsewhere on the board
VIN_IMU: C30.1, R33.2, U9.1 (VIN), U9.3 (ON/~OFF)

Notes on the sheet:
Sensors -- IMU / mag / baro / log flash

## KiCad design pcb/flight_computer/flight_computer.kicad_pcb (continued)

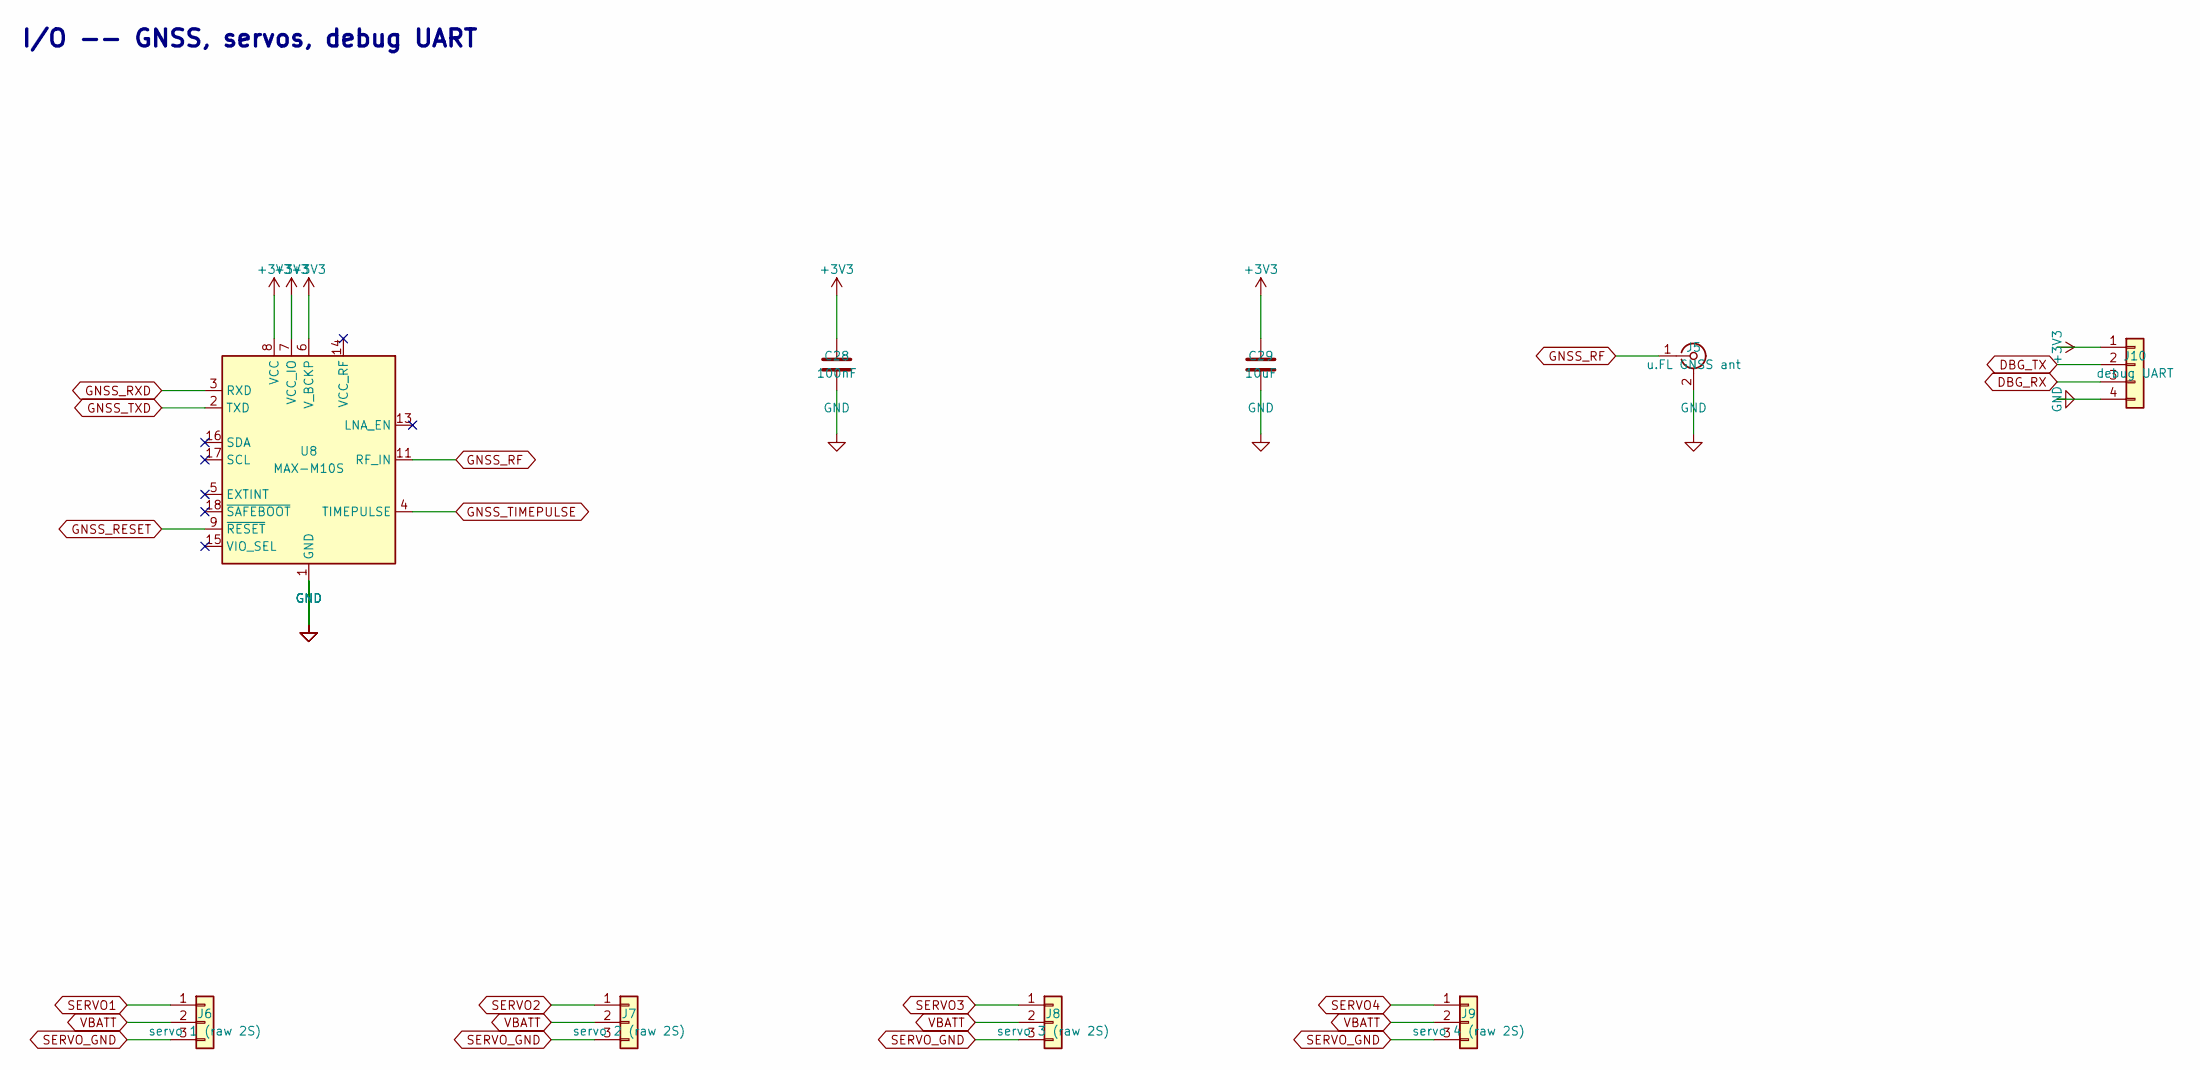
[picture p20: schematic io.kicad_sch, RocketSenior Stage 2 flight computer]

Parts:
C28: 100nF; C_0402_1005Metric
C29: 10uF; C_0805_2012Metric
J5: u.FL GNSS ant; U.FL_Hirose_U.FL-R-SMT-1_Vertical
J6: servo 1 (raw 2S); PinHeader_1x03_P2.54mm_Vertical
J7: servo 2 (raw 2S); PinHeader_1x03_P2.54mm_Vertical
J8: servo 3 (raw 2S); PinHeader_1x03_P2.54mm_Vertical
J9: servo 4 (raw 2S); PinHeader_1x03_P2.54mm_Vertical
J10: debug UART; PinHeader_1x04_P2.54mm_Vertical
U8: MAX-M10S; ublox_MAX

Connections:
+3V3: C28.1, C29.1, J10.1, U8.6 (V_BCKP), U8.7 (VCC_IO), U8.8 (VCC); also elsewhere on the board
DBG_RX: J10.3; also elsewhere on the board
DBG_TX: J10.2; also elsewhere on the board
GND: C28.2, C29.2, J5.2 (Ext), J10.4, U8.1 (GND), U8.10 (GND), U8.12 (GND); also elsewhere on the board
GNSS_RESET: U8.9 (~RESET); also elsewhere on the board
GNSS_RF: J5.1 (In), U8.11 (RF_IN)
GNSS_RXD: U8.3 (RXD); also elsewhere on the board
GNSS_TIMEPULSE: U8.4 (TIMEPULSE); also elsewhere on the board
GNSS_TXD: U8.2 (TXD); also elsewhere on the board
SERVO1: J6.1; also elsewhere on the board
SERVO2: J7.1; also elsewhere on the board
SERVO3: J8.1; also elsewhere on the board
SERVO4: J9.1; also elsewhere on the board
SERVO_GND: J6.3, J7.3, J8.3, J9.3; also elsewhere on the board
VBATT: J6.2, J7.2, J8.2, J9.2; also elsewhere on the board

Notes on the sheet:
I/O -- GNSS, servos, debug UART

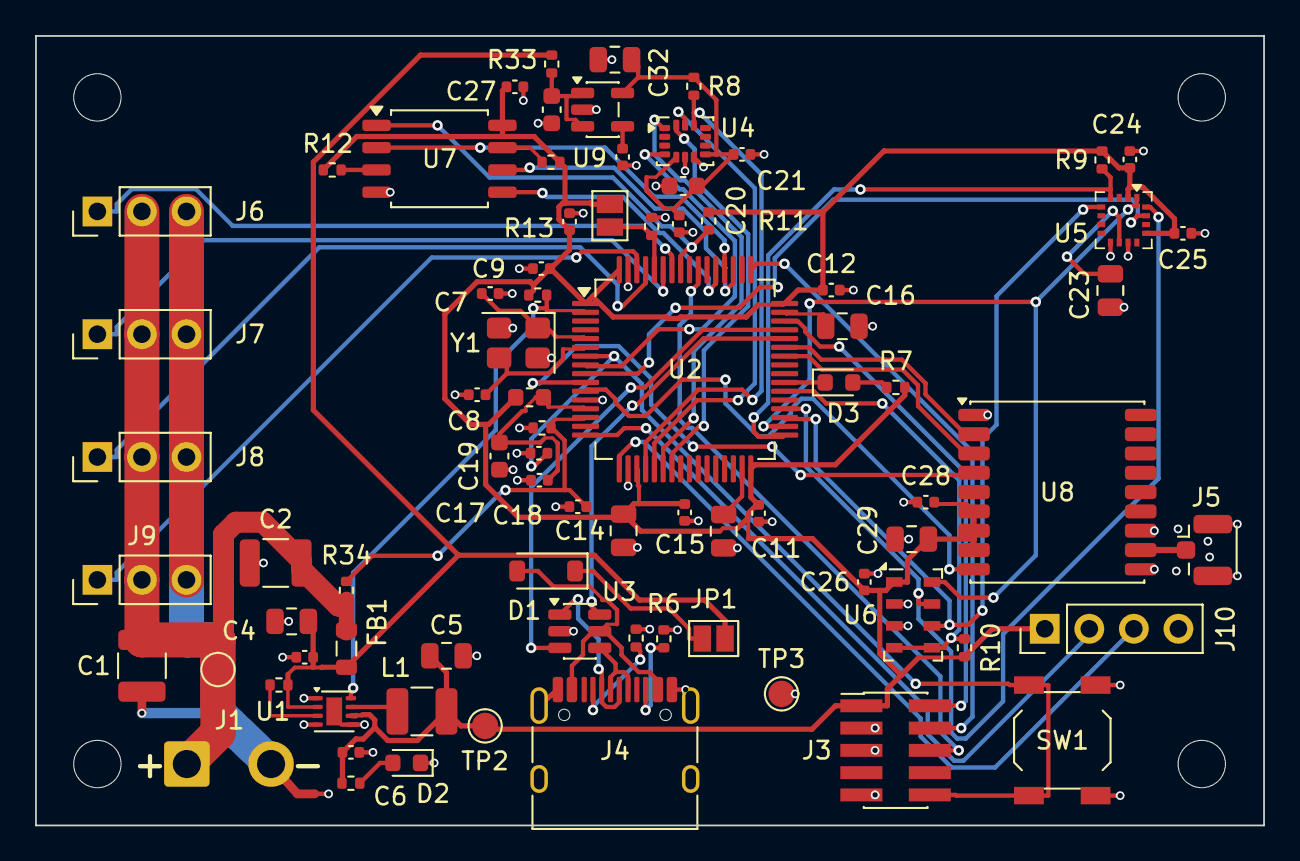
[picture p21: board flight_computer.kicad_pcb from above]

Board: 4 copper layers, 70.0 x 45.0 mm, 85 parts (0 on the bottom side), 62 nets.

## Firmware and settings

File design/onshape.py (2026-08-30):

"""Minimal Onshape REST client.

The CAD for this project is driven through the API, not the browser. That is a
deliberate choice and it has already paid for itself: reading the feature tree as
JSON exposed two defects that weeks of clicking had hidden (a hinge dimension taken
to a circle's tangent instead of its centre, and a datum plane that drove no
geometry). See docs/01-next-steps.md.

Credentials are NEVER stored in the repo. They are read at call time from
~/.onshape_keys, which may be either JSON with access_key/secret_key fields or a
flat KEY=VALUE / two-line file. Nothing in this module prints, logs, or returns a
secret; only the derived Authorization header is constructed, and that stays local
to the request.
"""

from __future__ import annotations

import base64
import json
import os
import time
import urllib.error
import urllib.parse
import urllib.request
from pathlib import Path

BASE = "https://cad.onshape.com/api/v10"

_KEYFILE = Path(os.environ.get("ONSHAPE_KEYS", Path.home() / ".onshape_keys"))

# Field names seen in the wild for the same two values.
_ACCESS_NAMES = ("access_key", "accesskey", "access", "onshape_access_key", "api_key", "key")
_SECRET_NAMES = ("secret_key", "secretkey", "secret", "onshape_secret_key", "api_secret")


def _credentials() -> tuple[str, str]:
    """Return (access_key, secret_key). Tolerates several plausible file layouts."""
    env_a, env_s = os.environ.get("ONSHAPE_ACCESS_KEY"), os.environ.get("ONSHAPE_SECRET_KEY")
    if env_a and env_s:
        return env_a, env_s

    if not _KEYFILE.exists():
        raise SystemExit(
            f"No Onshape credentials: {_KEYFILE} not found and "
            "ONSHAPE_ACCESS_KEY / ONSHAPE_SECRET_KEY are unset."
        )

    text = _KEYFILE.read_text()

    # 1. JSON object, possibly nested one level.
    try:
        data = json.loads(text)
    except json.JSONDecodeError:
        data = None
    if isinstance(data, dict):
        flat: dict[str, str] = {}
        for k, v in data.items():
            if isinstance(v, dict):
                for k2, v2 in v.items():
                    flat[k2.strip().lower()] = str(v2)
            else:
                flat[k.strip().lower()] = str(v)
        a = next((flat[n] for n in _ACCESS_NAMES if n in flat), None)
        s = next((flat[n] for n in _SECRET_NAMES if n in flat), None)
        if a and s:
            return a, s

    # 2. KEY=VALUE or KEY: VALUE lines.
    kv: dict[str, str] = {}
    bare: list[str] = []
    for raw in text.splitlines():
        line = raw.strip().lstrip("export ").strip()
        if not line or line.startswith("#"):
            continue
        for sep in ("=", ":"):
            if sep in line:
                k, _, v = line.partition(sep)
                kv[k.strip().strip('"').lower()] = v.strip().strip('",')
                break
        else:
            bare.append(line)
    a = next((kv[n] for n in _ACCESS_NAMES if n in kv), None)
    s = next((kv[n] for n in _SECRET_NAMES if n in kv), None)
    if a and s:
        return a, s

    # 3. Two bare lines, access then secret.
    if len(bare) >= 2:
        return bare[0], bare[1]

    raise SystemExit(
        f"Could not parse Onshape credentials from {_KEYFILE}. Expected JSON with "
        "access_key/secret_key, KEY=VALUE lines, or two bare lines (access, then secret)."
    )


def _auth_header() -> str:
    a, s = _credentials()
    return "Basic " + base64.b64encode(f"{a}:{s}".encode()).decode()


# Onshape rate-limits sustained scripted use with HTTP 429, and there is no documented
# budget. A single call almost always succeeds; it is the scripts that make dozens in a
# row -- canard_sweep.py, make_hinge_stack.py, anything that walks every part's mass
# properties -- that trip it, and they then fail HALFWAY THROUGH, which for a write
# sequence is the worst possible place to stop.
#
# Retrying is safe: a 429 means the request was REJECTED, not applied, so a retried POST
# or DELETE cannot double-apply. Back off exponentially and honour Retry-After when the
# server sends one.
RETRY_STATUS = {429, 502, 503, 504}
MAX_RETRIES = 6
BACKOFF_BASE = 8.0  # seconds; 8, 16, 32, 64, 128, 256 -- about 8 minutes in total

# NEVER sleep for an arbitrary Retry-After. Onshape's 429 is not only a burst limit: it
# also enforces a LONG-WINDOW quota, and when that one is exhausted the server answers
# with a Retry-After measured in HOURS -- 49699 seconds, just under fourteen, was the
# value seen on 2026-08-30. Honouring that literally turns a script into a process that
# looks like it is working for the rest of the day.
#
# So cap it. Past the cap the right behaviour is to fail immediately and say WHEN the
# quota comes back, because that is a fact the caller can act on and a sleeping process
# is not.
MAX_RETRY_AFTER = 300.0  # seconds


def call(method: str, path: str, body: dict | None = None, query: dict | None = None):
    """One API call. `path` is relative to the API root, e.g. '/documents'.

    Retries on 429 and on transient 5xx, with exponential backoff. Everything else
    raises immediately, because a 400 will not get better by being asked again.
    """
    url = BASE + path
    if query:
        url += "?" + urllib.parse.urlencode(query)
    payload = json.dumps(body).encode() if body is not None else None

    for attempt in range(MAX_RETRIES + 1):
        req = urllib.request.Request(url, data=payload, method=method)
        req.add_header("Authorization", _auth_header())
        req.add_header("Accept", "application/json;charset=UTF-8;qs=0.09")
        if payload is not None:
            req.add_header("Content-Type", "application/json")
        try:
            with urllib.request.urlopen(req, timeout=120) as resp:
                raw = resp.read()
            break
        except urllib.error.HTTPError as e:
            detail = e.read().decode(errors="replace")[:2000]
            if e.code in RETRY_STATUS and attempt < MAX_RETRIES:
                wait = float(e.headers.get("Retry-After") or BACKOFF_BASE * 2 ** attempt)
                if wait > MAX_RETRY_AFTER:
                    resets = time.strftime("%a %H:%M", time.localtime(time.time() + wait))
                    raise RuntimeError(
                        f"{method} {path} -> HTTP {e.code}\n"
                        f"Onshape wants {wait:.0f}s ({wait / 3600:.1f} h) before the next "
                        f"request, which means the long-window API quota is spent, not "
                        f"that this was a burst.\nIt comes back about {resets}. Nothing "
                        f"was written by this call. Re-run then; do not sit and wait."
                    ) from None
                print(f"    [onshape] HTTP {e.code} on {method} {path.split('?')[0]}; "
                      f"retrying in {wait:.0f}s "
                      f"({attempt + 1}/{MAX_RETRIES})", flush=True)
                time.sleep(wait)
                continue
            raise RuntimeError(f"{method} {path} -> HTTP {e.code}\n{detail}") from None
    if not raw:
        return None
    try:
        return json.loads(raw)
    except json.JSONDecodeError:
        return raw.decode(errors="replace")


def get(path, **query):
    return call("GET", path, query=query or None)


def post(path, body, **query):
    return call("POST", path, body=body, query=query or None)


if __name__ == "__main__":
    me = get("/users/sessioninfo")
    print("authenticated as:", me.get("name") or me.get("email", "?"))

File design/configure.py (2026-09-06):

"""Turn a compact parameter set into a full vehicle, and score it against requirements.

Layout, nose to tail:

    [nose cone] [nav bay] [canard module] [recovery bay] [booster + aft fins]

The nav bay is forward on purpose: GNSS antennas need sky view and want to be as far as
possible from the servo power wiring, and a fiberglass airframe is an RF shield, so the
antenna wants to sit under the (thin, non-conductive) nose shoulder region.
"""

from __future__ import annotations

import math
from dataclasses import dataclass, field, replace
from functools import lru_cache
from pathlib import Path

from . import aero, avionics, control, joints, mass as mass_mod, recovery, trajectory
from .geometry import BodyTube, FinSet, NoseCone, Rocket
from .motors import GENERIC, Motor, load_eng
from .packaging import SERVOS


@dataclass
class DesignParams:
    outer_diameter: float
    wall_thickness: float
    motor: Motor
    nose_fineness: float = 4.0
    nose_shape: str = "ogive"
    nav_bay_cal: float = 1.6  # bay lengths in calibers
    canard_module_cal: float = 1.8
    # 4.5 cal, and it is now CHECKED rather than assumed. It was a number someone typed,
    # and recovery.check_packing() exists because nothing had ever verified it. The first
    # run said it was 11 mm short -- but that verdict came from estimating packed volume as
    # budgeted mass / an assumed bulk density, and the budget carries a 280 g main against
    # a real Fruity Chutes Iris Ultra 60" Compact at 193 g. With the vendor's published
    # pack volumes standing in for the estimate, the hardware needs 4.33 cal and this bay
    # fits it with 13 mm to spare. The airframe was right; only the confidence in it was
    # missing. See design/recovery.py for the sourced numbers.
    recovery_bay_cal: float = 4.5
    booster_margin_cal: float = 1.2  # booster length beyond the motor
    # 1.30 cal, up from 0.85, and this is where the agility actually comes from.
    # Canard area buys Cm_delta directly and costs static margin, and at 1.30/1.70 the
    # vehicle trims at 1.90 cal nominal instead of 2.22 -- more lean per degree of throw,
    # which is worth far more than the canard's own normal force. See
    # scripts/agility_sweep.py stage 4 for what each tenth of a caliber costs in risk.
    # 1.30 -> 1.45 cal AT THE STRETCH FREEZE (Sep 2026, correction 62), and it is here
    # because correction 61's HINGE fix made it legal, not because anything aerodynamic
    # changed. 1.45 cal was scored and rejected twice before: the pre-freeze search had it
    # stopped at a 1.92x bearing margin against 2.0x, and the whole point of docs/12 section
    # 5 is that the hinge -- not stall, not static margin, not servo torque -- was the wall.
    # Correction 61 took the journal dia 6 -> dia 8 to make the 1.30 cal vehicle legal on a
    # horizontal launch, and that bought 2.27x at 1.45 cal as a side effect. The wall moved,
    # so the canard could.
    #
    # It is better than 1.30/1.70 on BOTH axes at once, which is rare enough to say plainly:
    # 8.97 -> 9.92 deg/s of peak heading rate AND P(SM < 1.0) 0.61% -> 0.45%. Growing the
    # aft set with it is what does that -- see aft_semispan_cal below. Turn radius
    # 990 -> 880 m.
    canard_semispan_cal: float = 1.45
    # Root chord and taper are set TOGETHER and hold panel area constant at 3188 mm^2.
    # 0.85/0.40 replaced 0.70/0.70 in Aug 2026: at the 35.4 deg sweep below, a more
    # sharply tapered panel recovers most of the authority the sweep costs (1.82 -> 1.93 g,
    # 394 -> 418 m of crossrange) because CNa rises as the tip unloads. It also reads more
    # like a real missile canard, which is why it was chosen -- the aerodynamics came out
    # ahead as well, which is rare enough to note.
    #
    # The cost is flutter: the root chord grows 55.6 -> 67.5 mm at a fixed 3.0 mm thickness,
    # so t/c falls 0.054 -> 0.044. This is now the parameter to watch if the panel ever
    # gets thinner. See docs/00-requirements.md section 8.
    #
    # THE FLUTTER MARGINS IN THIS PARAGRAPH'S HISTORY (5.42x -> 4.46x) WERE MEASURED AT THE
    # OLD 0.85 cal SEMISPAN and no longer describe this vehicle. At 1.30 cal the canard
    # aspect ratio is 2.18 and the margin is 3.50x -- still comfortably over 1.5x, and the
    # canards are not the flutter-critical set. The aft fins are, at 2.13x. Both are
    # regenerated by scripts/baseline.py; do not quote these numbers, run it.
    # 0.85 -> 1.1161 cal AND taper 0.40 -> 0.10 (correction 63). A COSMETIC change, asked
    # for as one and priced as one: the trapezoid read as a clipped panel with a wide tip
    # and the vehicle is meant to look like a canard missile. Root 67.5 -> 88.6 mm, tip
    # 27.0 -> 8.9 mm -- a 10:1 taper against 2.5:1 -- with the leading edge at 42.2 deg.
    #
    # THE RULE ABOVE STILL HOLDS, and it is why the root grew: root chord and taper are set
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

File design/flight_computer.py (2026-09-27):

"""Stage 2 flight computer -- the parts, and the three questions nobody had asked.

`docs/06` closed D7 by selecting a custom STM32F405 board for the guided vehicle, with the
ejection charges left on an independent commercial altimeter. `docs/07` and
`design/estimation.py` then named the sensor set and computed what it has to achieve. What
neither of them did was specify the board to the point where PARTS CAN BE ORDERED, and
three things stood between the two:

  1. A CONTRADICTION. docs/06 asks for a gyro with selectable full scale to +/-4000 deg/s.
     The named part, ICM-42688-P, tops out at +/-2000, and the only +/-4000 entry in
     estimation.py was `GYRO_WIDE` -- `measured=False`, no real part behind it. A
     requirement satisfied only by a part that does not exist is not a requirement, which
     is estimation.py's own rule turned on estimation.py. RESOLVED BELOW, and the answer is
     to drop the +/-4000 requirement rather than to buy it.

  2. NO POWER BUDGET ANYWHERE IN THE PROJECT. The battery was a bare line in `mass.py`
     ("2S 1500 mAh, 90 g") with no voltage, no watt-hours, no draw and no runtime, and
     `packaging.Servo` modelled the KST X08 Plus for torque and speed only. Nothing had
     ever asked whether the pack covers a flight. It does -- by about an order of
     magnitude -- and the finding is that CAPACITY WAS NEVER THE CONSTRAINT. Peak current
     is, and that is a wire and connector question, not a battery one.

  3. LOGGING HAD NEVER BEEN TURNED INTO BYTES. `avionics.board_requirements()` asks for
     "at least 100 Hz for 150 s" and its own slack note says "onboard flash is enough".
     Written out as a channel list it is not: the F405's 1 MB is short by about 3x, and it
     is short because of the one channel the thesis actually needs.

EVERY RATE, DURATION AND LOAD HERE IS DERIVED FROM `configure.evaluate()`. What is NOT
derived is the parts: those are datasheet numbers, marked `measured` and noted with the
source, exactly as `estimation.SensorSpec` and `avionics.Component` do it. Where a figure
had to be read off a curve rather than a table, the note says so -- see `SERVO_ACTIVE_A`,
which is the least precise number in this file and the one two findings rest on.

Regenerate with `python scripts/flight_computer_report.py`; the verdict is carried by
`scripts/baseline.py` so it cannot silently regress. Write-up in
`docs/14-flight-computer-bom.md`.
"""

from __future__ import annotations

from dataclasses import dataclass, field

from . import control
from . import estimation as est
from . import packaging

# Required ratio of available to required, matching every other module in this project
# (hinge.py, bay.py, motor_mount.py, seal.py). Applied here to battery energy and to
# storage capacity.
MARGIN_REQUIRED = 2.0

# How long the vehicle sits on the pad, armed, before the button is pushed. THIS IS THE
# ENERGY BUDGET'S DRIVING CASE and it is not a flight number: the flight is about two
# minutes and the pad is up to an hour. A capacity check run over the flight alone answers
# the wrong question by a factor of thirty.
PAD_TIME_S = 3600.0

# Reserve fraction of the pack that is not usable. A LiPo taken below ~20% under load sags,
# and a scrubbed launch that gets recycled wants the margin too.
BATTERY_USABLE_FRACTION = 0.80

# Buck converter efficiency, 2S down to 3.3 V. 0.85 is conservative for a modern synchronous
# part at these currents; it makes the logic rail look worse, not better.
BUCK_EFFICIENCY = 0.85

# Descent rate used ONLY to bound the logging and power window. `configure.py` sizes the
# main canopy for 5.0 m/s and the drogue leg is much faster, so treating the WHOLE descent
# as if it ran at the main's rate overstates the time. That is deliberate: this constant can
# only ever make the log buffer and the battery reserve too big, never too small. It is not
# a vehicle number and nothing else should import it.
DESCENT_RATE_BOUND = 5.0  # m/s

# R15's two launch elevations. NOT in configure.py -- `scripts/sil_demo.py` carries them the
# same way and says so, because the freeze is a rail angle rather than a vehicle parameter.
# 28 deg is the horizontal mode and it is the SIZING one here: a flat flight's max q is
# ~15.5 kPa against ~12.4 vertical, hinge moment goes as q, and so does servo current.
LAUNCH_ELEVATION_DEG = 28.0


# ---------------------------------------------------------------------------------------
# Parts
# ---------------------------------------------------------------------------------------
@dataclass(frozen=True)
class PartSpec:
    """One orderable line of the BOM.

    `measured` carries the same meaning it does in `estimation.SensorSpec` and
    `avionics.Component`: True means the numbers came off a named part's datasheet and the
    note says which. Nothing here has been bought.

    `current_ma` is the ACTIVE draw on the part's own rail, at the operating point this
    vehicle uses it at -- not a datasheet headline. A GNSS receiver in cold acquisition and
    the same receiver tracking are different numbers, and the budget wants the one it runs
    at for an hour on the pad.
    """

    name: str
    mpn: str
    package: str
    interface: str
    unit_price_usd: float
    qty: int = 1
    mass_kg: float = 0.0
    current_ma: float = 0.0
    rail_v: float = 3.3
    measured: bool = False
    note: str = ""

    @property
    def line_price(self) -> float:
        return self.unit_price_usd * self.qty


# --- the board ---------------------------------------------------------------------------
MCU = PartSpec(
    "MCU", "STM32F405RGT6", "LQFP64", "SPI x3, UART, TIM, SDIO", 10.00,
    mass_kg=0.0005, current_ma=86.0, measured=True,
    note="ST DS8626: 168 MHz Cortex-M4F, 1 MB flash, 192 KB RAM. 86 mA typ at 168 MHz with "
         "all peripherals enabled and ART on -- the conservative row, not the 238 uA/MHz "
         "headline. LQFP64 was chosen in docs/06 partly because it is hand-solderable, "
         "which is what makes a one-board spin recoverable")

IMU = PartSpec(
    "IMU", "ICM-42688-P", "LGA-14, 2.5 x 3.0 mm", "SPI (CS1)", 8.00,
    mass_kg=0.0002, current_ma=0.88, measured=True,
    note="TDK: +/-2000 dps, +/-16 g, 32 kHz max ODR, SPI to 24 MHz, 0.0028 deg/sqrt(s) ARW, "
         "+/-0.5% sensitivity tolerance. SELECTED -- see the gyro resolution below. It is "
         "also the part with the deepest ArduPilot/Betaflight driver history, which for a "
         "first board is worth more than any spec line on the alternative")
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

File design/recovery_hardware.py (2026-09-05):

"""The U-bolt, its backing plate and the ejection charge well -- the three parts every
bulkhead script in this project has refused to draw.

THE GAP THIS FILE CLOSES. The U-bolt HOLES have been in the CAD since correction 50
(`scripts/make_seal_cad_fusion.py`, from `seal.hole_layout()`'s own positions). The hardware
standing proud of them has never existed. Three scripts say so in their own docstrings and
one of them is blunt about which one matters -- `scripts/make_bulkhead_cad.py`: *"The
backing plate is the one that matters -- it is STRUCTURE (`seal.point_load_stress` goes as
the log of the plate-to-footprint radius ratio) -- and it is not here, so this part is not
yet the whole harness anchor."* `design/seal.py` says the same thing twice more, at
`UBOLT_HOLE_DIAMETER` and at the end of `check_hole_layout()`.

THE ANSWER, STATED BEFORE THE ARITHMETIC BECAUSE IT IS THE ONE IDEA IN THIS FILE: **a
U-bolt used as a harness anchor is not loaded the way a U-bolt is rated, and the size this
project assumed does not carry its own load.** `seal.py` has carried, since it was written,
the aside that settled the question without asking it: *"An M5 U-bolt on a 25 mm leg spacing
is the ordinary size for this load -- 1.3 kN through two 5 mm legs is 33 MPa of shear in
stainless, which is nothing."* Two things are wrong with that sentence and they compound.

  1. **THE LEGS ARE NOT IN SHEAR.** The harness pulls along the bolt's axis, away from the
     plate. The legs are in TENSION and the nuts react it. Shear never enters.
  2. **THE LEGS ARE NOT WHAT BREAKS.** What breaks is the CROWN, in bending, at the two
     bends where it meets the legs -- which is where U-bolts used as anchors are actually
     observed to straighten. A published U-bolt load rating is for CLAMPING A PIPE, where
     the crown bears on the pipe and the legs really are in tension and nothing bends. Using
     that rating for an anchor compares two different structures.

Sized against the mode that governs, the anchor is **M8 rather than M5**, which means the
5.5 mm holes already cut in both existing bulkheads become 8.5 mm. That is the cost of the
finding and it is cheap: they are not drilled yet.

TWO MORE THINGS FELL OUT, AND BOTH ARE GEOMETRY NOBODY HAD RUN.

  * **THE HARNESS DOES NOT FIT THROUGH THE U-BOLT.** `recovery.size_harness()` selects 3/4"
    tubular nylon -- 19.1 mm of webbing. An M8 U-bolt on `seal.UBOLT_LEG_SPACING` leaves a
    17.0 mm clear opening. Two sized parts of this vehicle, and nothing had ever put them
    next to each other. Opening the U-bolt up until the webbing passes drives it to M10 and
    ~310 g of stainless across four anchors, which is not the answer. The answer is that the
    webbing was never supposed to pass through it: `recovery.HARNESS_HARDWARE_KG` has priced
    "links and swivels" since it was written, and **the harness attaches through a QUICK LINK
    and the link goes through the U-bolt.** A 6 mm link needs 8 mm of opening, not 21. This
    file records that as a requirement rather than leaving it as the thing everybody happens
    to do.
  * **THE INTERNAL BULKHEAD'S CONDUIT HOLE IS IN THE WORST PLACE FOR A BACKING PLATE.**
    `seal.hole_layout()` puts it at 45 degrees "so it is equidistant from both U-bolt legs"
    -- a good choice made when the only things on that face were holes. A backing plate
    spans the legs, so its footprint is long in Y and narrow in X, and 45 degrees is exactly
    where it reaches furthest. Moved to 0 degrees, PERPENDICULAR to the legs, where the plate
    is narrow, it clears by 4.1 mm instead of overlapping by 2.5. Same radius, same stress,
    same everything the placement was chosen for.

WHAT SIZES THE BACKING PLATE, WHICH IS NOT WHAT SIZES MOST PLATES. Its own bending needs
1.2 mm. What it is FOR is the log term in `Bulkhead.point_load_stress()`: the plate sets
`footprint_radius`, and the disc's stress falls as the log of the ratio. `seal.py` has always
passed a hardcoded 6.0 mm there -- a bare nut face -- and said in a comment that this was
the number a real plate would replace. Replaced, the aft gas seal's U-bolt margin goes
**5.34x to 9.09x**. That is a result of the part existing, not a retune: nothing was
softened to get it, and `seal.py`'s default is unchanged so every previously reported number
still reproduces.
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

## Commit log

2026-08-28 Preliminary sizing tool, requirements, and OpenRocket correlation
    Senior capstone: canard-guided high power rocket. This is the baseline
    commit covering the preliminary sizing work that precedes any CAD.
    design/ Barrowman CNa/CP buildup, component drag, geometric mass and CG,
    US Std Atmosphere 1976, 3-DOF RK4 ascent, dual-deploy recovery
    sizing, actuator bay packaging with hinge moments, and canard
    pitch/roll authority including canard-wake-on-aft-fin interference.
    scripts/ Packaging report, ThrustCurve.org .eng fetch, motor trade across
    102 real L2 motors, burn time and recovery studies, static margin
    Monte Carlo, requirement swee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
    [aero.py, atmosphere.py, configure.py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]
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2026-08-28 Collapse six copies of the baseline into one canonical definition
    Step 3 asks for a frozen DesignParams in design/configure.py. Until now the
    baseline lived in six places -- baseline.py, robustness.py, make_ork.py,
    motor_trade.py, burn_time_study.py and recovery_study.py each carried their own
    outer_diameter / wall_thickness / semispan / motor-path literals. They happened
    to agree, but nothing enforced it, and they had already drifted away from the
    documentation once.
    design/configure.py is now the single source of truth:
    * fin semispans are the DesignParams defaults (canard 0.85, aft 1.55 cal).
    They were 0.45 / 1.05 -- the superseded airframe -- so any code path that
    built Desig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
    [configure.py, flutter.py, recovery.py]
2026-08-28 Fix inverted canard hinge sign convention
    The hinge line sat at 0.30c against a 0.25c panel CP -- aft of the CP, which
    makes the normal force act ahead of the hinge and drive the panel toward
    greater deflection. That is a divergent, overbalanced control surface. Both the
    hinge_moment() docstring and docs/01-next-steps.md asserted the opposite, that a
    hinge aft of the CP is "weakly self-centring". Self-centring requires the hinge
    FORWARD of the CP.
    The abs() on hinge_moment()'s return threw the sign away, so nothing downstream
    could have caught it.
    * hinge_moment() now returns a signed value: positive is restoring (hinge
    forward of CP), negative is divergent. The docstring states the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
    [control.py, packaging.py]
2026-08-28 Freeze against real servos: KST X08 Plus and MKS HV6100
    Adds both shortlisted parts to packaging.SERVOS with datasheet values, and
    makes the servo choice part of the frozen design rather than a constant that
    each script picked for itself.
    Root cause this exposed: servo mass and servo packaging were never connected.
    configure.evaluate() built the mass budget with mass.py's 55 g default while
    baseline.py separately checked a 20 g size class, and make_ork.py,
    openrocket_check.py and robustness.py each had their own build_mass call with
    the same default. Five sites, one of which fed the .ork, so the OpenRocket
    correlation was validating a mass the tool never used.
    DesignParams.servo is now a k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
    [configure.py, packaging.py]
2026-08-28 Make nose ballast part of the frozen design
    DesignParams gains nose_ballast_kg (0.100) and nose_ballast_station (0.191 m).
    build_mass() places it as a real mass item, and configure, make_ork and
    openrocket_check all pass it through, so the baseline now describes the vehicle
    that would actually fly rather than one that fails R1.
    wet mass 5.99 -> 6.10 kg
    wet CG 852.4 -> 841.3 mm
    static margin 1.83 -> 1.97 cal at rail exit
    apogee 1409 -> 1379 m
    crossrange 513 -> 450 m
    P(SM < 1.0) 1.8% -> 0.6% <-- R1 satisfied
    robustness.py's ballast argument is now ABSOLUTE rather than additional and
    defaults to the design's value, so the headline run describes th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
    [configure.py, mass.py]
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2026-08-29 Correct the actuator packaging premise; close the Step 1 risks
    Confirmed against the hardware: the servo output shaft is on a large face, not
    an end face. That makes check_flat_mount() the arrangement being built and
    retires the assumption section 4 was constructed on.
    Consequences, none of which move a design number but several of which change
    what the design is ALLOWED to be:
    * Actuator packaging is not a binding constraint. Four servos need 106 mm of
    arc against 188 mm available, leaving a 45 mm central void -- not the
    +2.3 mm knife edge that drove servo selection for weeks.
    * The mounting-lug risk is retired. The lugs extend the length axis, which no
    longer competes for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
    [packaging.py]
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2026-08-29 Add CAD profiles and a canard module build sheet
    scripts/make_cad_profiles.py emits DXF R12 geometry straight from the frozen
    DesignParams, so the CAD cannot drift from the analysis:
    canard_planform.dxf panel outline, hinge axis and panel CP on own layers
    aft_fin_planform.dxf outline including a 12 mm through-wall tab
    canard_bay_section.dxf tube OD/ID, 4 servo footprints, shaft locations
    Hand-written DXF, no CAD kernel needed. The hinge axis is placed at 0.20 MAC
    (13.5 mm aft of the canard root LE) against a panel CP at 0.25 MAC (15.9 mm), so
    the geometry carries the corrected sign convention rather than leaving it to be
    remembered.
    docs/05-canard-module-build.md is the mode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
    [aft_fin_planform.dxf, canard_bay_section.dxf, canard_planform.dxf]
2026-08-30 Check the recovery bay against the hardware, and confirm 4.5 cal was right
    `recovery_bay_cal = 4.5` was a number someone typed. Nothing had ever checked
    it, which is a bad property for a frozen dimension whether or not the number
    turns out to be correct.
    design/recovery.py grows a packing model: soft goods sized from the recovery
    mass budget (so the packing check and the mass check cannot disagree), two
    separately-pressurised compartments, a fill limit, and bulkhead allowances.
    evaluate() now fails any design whose recovery hardware does not fit, so this
    class of error cannot come back.
    The check initially said the bay was 11 mm short, and the airframe was briefly
    lengthened to 5.1 cal on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
    [configure.py, packaging.py, recovery.py]
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2026-08-30 Feed the measured canard module inertia into control.py
    The Onshape model is rebuilt to the 35.4 deg / 0.40 taper planform, so its mass
    properties are now worth something. estimate_inertia() takes them.
    canard module (13 parts) 0.2604 kg
    CoM X 0, Y 0, Z 72.418 mm aft of the module face
    inertia about that CoM Lxx = Lyy = 601.588, Lzz = 623.179 kg mm^2
    every off-diagonal zero
    This is superposition, not a drop-in replacement: the measured component is
    removed from the crude bulk term and added back with its real tensor plus a
    parallel-axis term, which is exact. Everything else is still a thin-walled
    shell in roll and a slender ro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
    [control.py]
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2026-08-30 Fix the hinge station: the shaft was at 0.029 of MAC, not 0.200
    Switched the CAD work from browser automation to the Onshape REST API. The
    first read of the feature tree as JSON exposed two defects that months of
    clicking had hidden, both in the geometry that sets the hinge line.
    1. Sketch 3's hinge dimension measured to the CIRCLE'S TANGENT, not its centre.
    It read "57.2 mm" while the shaft axis sat at 59.700 -- off by exactly the
    2.5 mm shaft radius. A dimension that says one thing and means another.
    2. The "Hinge Plane" datum drove nothing. Sketch 3 and Sketch 4 are built on
    plane JEC, not on it, so editing its offset moved the plane and no geometry.
    An earlier edit of that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
    [control.py]
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2026-08-30 Make the canard hinge a mechanism: real servos, articulation, and a bearing
    Two sessions' work in one commit, because they share too many files to split
    cleanly, and the second only happened because of the first.
    The servo is no longer a bounding box. KST X08 Plus built from the
    manufacturer's dimensioned drawing in its own Part Studio, instanced four
    times into Assembly 1, articulated by a FeatureScript custom feature
    (cad/canard_articulation.fs) that scripts/canard_sweep.py drives. The real
    part immediately contradicted two things every document here had asserted:
    the output shaft is 6.14 mm from one case end, not centred at 11.75, and it
    runs along the 16.8 mm axis, not the 8 mm one.
    Cl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
    [control.py, hinge.py, onshape.py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]
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2026-08-30 The tang was sized against stress; the binding constraint was geometry
    Trying to actually build the tang in CAD found two things the stress
    model could not.
    The panel is swept 35.4 degrees, so its leading edge runs aft 0.71 mm per
    mm of span while the tang stays in a fixed axial band about the hinge
    axis -- it has to, being the end of a shaft that turns about that axis.
    Depth is therefore paid for in leading-edge material at better than half
    a millimetre per millimetre, and the previous rationale had it exactly
    backwards: "depth is bought cheaply, it improves everything at once and
    is paid for nowhere."
    30 mm of engagement left 2.26 mm of panel ahead of the tang tip. Worse,
    the 60%-of-chor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
    [hinge.py]
2026-08-30 Index the root joint by radius; the CAD found a datum error the analysis could not
    Reading the real Onshape model to plan the tang cut found that the
    analysis had been feeding a length measured from one datum into a
    function measured from another.
    `engagement` is measured from the PANEL ROOT FACE at R 40.200. The
    planform's sweep and semispan are measured from the THEORETICAL root at
    the tube surface, R 39.700. The 0.500 mm standoff between them was being
    ignored, which over-read the leading-edge clearance by 0.500 times the
    0.71 sweep gradient -- 5.50 mm reported against 5.14 mm real, on a 5.0 mm
    requirement.
    The analysis agreed with itself completely. It disagreed with Onshape,
    where pan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
    [hinge.py]
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2026-08-30 Take "I have to buy this" as a design constraint, and it finds a failing joint
    The panel joint was sized in dimensions rather than in parts you can
    order. Asking which G10 sheets to buy broke it open.
    THE BUG. skin_thickness was (panel - tang)/2. The slot is the tang plus a
    0.1 mm bond line on each face, so the real skin was 0.5 mm where the
    model said 0.6. Skin stress goes as 1/t^2, so the joint was at 1.69x
    against a 2.0x requirement while reporting 2.5x. RootJoint now carries
    bond_line and the skin spans slot_width, not tang_width. No stress review
    would have found this; being asked which sheet to order did, because it
    forces the stack into thicknesses that exist.
    THE PANEL. 0.6/1.8/0.6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
    [configure.py, hinge.py]
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2026-08-31 Apply the root tang to the CAD, and fix three FeatureScript bugs to do it
    Applied through the browser rather than the API, because the /features
    quota was still spent. Every result verified afterwards through /parts
    and /massproperties, which are not throttled.
    IN THE MODEL NOW, all four canards:
    panels 3.0 -> 3.2 mm, the laminate thickness
    shafts 746.856 mm^3 each against 746.856 predicted, material intact
    panels down by exactly 619.520 mm^3, which is the slot
    module 258.6426 -> 276.2319 g
    assembly 21 instances, 5 rigid groups and 4 revolute mates all survived
    THREE BUGS, and the first two were mine walking into things this project
    had already written down.
    `box` is a r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
    [control.py]
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2026-08-31 Build the hinge bearing, put four of them in the assembly, and fix the laminate
    The Onshape /features quota came back, so the queued CAD work went in.
    The bearing is the last part of the hinge that existed only as a number, and a
    part that is not modelled cannot collide with anything -- the same trap that hid
    a hard servo clash for weeks when the servo was a bounding box. It is now a real
    Part Studio, and all four are instanced in Assembly 1 on their hinge axes at
    R 39.700, in the airframe rigid group because a pressed race does not rotate with
    the panel. That is what the printed bay's housing collar gets drawn against.
    Volume reads 131.947 mm^3 against the analytic annulus to 0.001 mm^3,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
    [control.py, hinge.py]
2026-08-31 Build the printed canard bay, and correct the number that justified its collar
    One printed part, PETG-CF, 39 g, 41.5 mm long: four servo trays and four
    bearing collars. Plus eight small retainer bars. design/bay.py models it,
    cad/canard_bay.fs and scripts/make_bay_cad.py build it, scripts/bay_report.py
    prints the argument. It sits in Assembly 1 at identity, because it was drawn in
    the module's own frame -- unlike the bearings, which had to have a placement
    derived from a servo's transform.
    THE COLLAR IS WORTH 3.4x -> 14.5x, NOT 3.2x -> 21.3x.
    Every document here priced the collar by putting the whole 6.0 mm bearing length
    into p = 6M/(dL^2) + N/(dL). That is the formula for ONE material. T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
    [bay.py, control.py, materials.py]
2026-08-31 Close the coupling by casting the spline instead of cutting it, and fix the shaft material
    THE COUPLING.
    Correction 16 said "do not broach the spline, buy a horn". Correction 19 found
    that no horn fits. Both were circling the same constraint: there is 0.515 mm
    between the servo's output face and the bearing, everything outboard of that has
    to pass down the dia 6 journal, and fifteen teeth on a dia 4 pitch circle need
    enough metal around them that every female-spline part sold -- horn, hub, adapter
    -- is dia 7 or larger. Neither space will take one. And broaching a socket into a
    0.95 mm wall is the specialist operation correction 16 was trying to avoid.
    The way out is neither. Do not cut te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
    [control.py, hinge.py, materials.py]
2026-08-31 Audit the module against Onshape's own interference check, and fix six defects
    Asked to work through the details properly rather than re-run the happy path.
    The useful move was Onshape's assembly Check interference, which the REST API
    does not expose (/interferencecheck 404s) and which nothing here had ever run.
    It reported 17 interfering pairs. Every one of the six causes was invisible to
    part count, to mass, to evaluate(), and to the axis-aligned bounding box.
    - The TANG was modelled inside the tube wall, x4. Its 1.0 mm union overshoot
    started the blade at R 39.200 in a wall running 37.400 -> 39.700. Invisible
    because the tang is unioned INTO the shaft, so the shaft's box never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
    [bay.py, control.py, hinge.py]
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2026-08-31 Size the aft gas seal, which turned out not to be a seal
    docs/05 has carried "never sized" on this part for six months, and the reason it
    stayed unsized is in its name. A gas seal sounds like a gasket. This disc is the
    piston the ejection charge pushes on to separate the airframe (7213 N in the
    stuck-joint case) and the anchor the main parachute pulls on when it opens
    (1306 N). Gas tightness is its third requirement. Same error as corrections 2
    and 11: a part named after its smallest load and then sized against the number
    in its name.
    design/seal.py models it, scripts/seal_report.py prints the argument,
    scripts/baseline.py carries the verdict so it cannot silently regress.
    G-10, 4.8 mm, 39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
    [materials.py, seal.py]
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2026-08-31 Close everything the gas seal opened, and correct the seal's own vent argument
    Four items, and each turned out to be a different kind of problem.
    THE INTERNAL BULKHEAD was a 12.0 mm length allowance in recovery.py and nothing
    else. It is now the same model applied a second time: G-10 4.8 mm, 39 g, with a
    dia 6 feed-through for the conduit. Two things about it are worth knowing. It is
    the only pressure boundary in the vehicle with NO FUSE -- the aft seal has shear
    pins that go first by design, this one is bonded at both ends of its load path,
    so a stuck joint simply hands it the whole charge. And both bulkheads come out
    at the same pressure for a reason that belongs to neither of them:
    re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
    [avionics.py, configure.py, mass.py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]
2026-08-31 Move the tracker and radio into the nose, and find the shoulder question
    Correction 27 left the nav bay 49 mm short and listed four ways out. This is the
    second of them and the only one that costs nothing structural: the telemetry
    radio and the independent GPS tracker now ride in the nose, on the ballast rod,
    20 mm behind the washer stack.
    It is not a packing dodge. It is where a tracker belongs -- its job is to still
    be working when nothing else is, which argues for its own battery in its own
    compartment as far from the servo bus as the airframe allows, and the shoulder
    region is the one place a fibreglass airframe stops shielding an antenna.
    CHECKING IT NEEDED A NEW KIND OF CHECK. Every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
    [avionics.py, configure.py, geometry.py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]
2026-08-31 Settle the shoulder: a coupler is a tube, and its bore is still bay
    THE QUESTION HAD A FALSE PREMISE, and both of its answers were wrong. docs/04
    carries a 1 caliber shoulder on a 127 mm nav bay, and "which tube's length does
    it spend" had two readings 79 mm apart. Neither: a shoulder is a hollow tube, so
    is a coupler, and what is inside one is still bay. It costs local DIAMETER over
    its span -- 74.8 - 2 x 2.3 = 70.2 mm -- not length. What costs length is a
    bulkhead, and bulkheads were already counted. Correction 28's shape one joint
    further forward: a complete-sounding question that excluded the answer.
    design/joints.py models all four joints, because the shoulder turned out to be
    one inst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
    [avionics.py, configure.py, joints.py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]
2026-08-31 Fix the recovery bay margin by sizing the harness, which nobody ever had
    Correction 31 left the bay at +0.1 mm, which is not a pass, it is a coincidence.
    Every obvious lever was a bad one -- shave the fill limit, shorten the coupler,
    lengthen a frozen airframe. The margin came from somewhere nobody had looked.
    THE HARNESS IS A QUARTER OF THE BAY AND NOTHING HAD EVER SIZED IT. Its volume
    came from shock_cord_and_links = 0.220 kg divided by an assumed bulk density: an
    unchecked budget line turned into a volume by a guess. Its STRENGTH came from
    nowhere at all, though it carries every newton of the opening shock and its
    failure loses the vehicle and the data with it.
    The shock is 1.32 kN -- s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
    [configure.py, mass.py, recovery.py]
2026-08-31 Build both recovery bulkheads, and place the seal where it can be checked
    design/seal.py sized these in August and neither had ever been drawn, which is
    the condition corrections 11 and 18 both warn about: a part that is not modelled
    cannot collide with anything.
    Aft gas seal dia 74.8 x 4.8 G-10, 2 x dia 4.0 feed-through,
    2 x dia 5.5 U-bolt
    Recovery internal same disc, 1 x dia 6.0 for the conduit
    bulkhead
    Volumes verified against the analytic disc-less-holes to 0.000 mm3. That is the
    only proof the holes actually cut -- a solid disc and a drilled one differ by
    1.7% of mass, which no tolerance-based check would notice, and Part Studio 1's
    Ext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
    [seal.py]
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2026-09-01 Place the canard module vents, and the leak path is what chooses the band
    The module vent was decided as a SIZE (2 x dia 2 mm) and a SURFACE (its own wall,
    correction 28) and then handed to CAD with no station and no clocking. That is
    not something a hole can be drawn from, and it was the first thing the Onshape
    work ran into.
    station Z 120.0 mm from the module forward face
    clocking 45 and 225 deg -- opposed, each bisecting a canard gap
    size 2 x dia 2.0 mm, 6.28 mm2 (unchanged)
    THE Cp ARGUMENT THAT GOVERNS THE NAV BAY DOES NOT GOVERN THIS BAY, and that is
    why this could be settled at all. venting.py's header says the file "says nothing
    about port PLACEMENT ... because plac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
    [venting.py]
2026-09-01 Cut the module vents, and find that the pass-through has no plate
    Two jobs were queued as the last CAD in the canard module. One is done and one
    turned out to be blocked on a part nobody has ever sized.
    THE VENTS ARE IN. 2 x dia 2.0 mm at Z 120.0 mm, clocked 45 / 225 deg, cut by
    scripts/make_module_vents.py from the placement in design/venting.py. The script
    types no dimension of its own and is safe to re-run. Tube 146.4207 -> 146.3940 g,
    which is -26.7 mg against an analytic 2 x pi x 1^2 x 2.3 mm^3 of G10 -- the
    agreement is what proves the holes went RADIALLY through 2.3 mm of wall rather
    than obliquely through more.
    THE FIRST CUT WAS WRONG AND ONLY GEOMETRY COULD HAVE CAUGHT IT. It rege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
    [control.py, seal.py]
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2026-09-03 Draw the nav bay sled, and find 0.80 of the bore is too narrow
    The sled was the fourth allowance in this project to be priced without
    existing: mass.py has charged 150 g for sled_and_hardware since that dict was
    written and avionics.SLED_WIDTH_FRACTION set its width, for a part nobody had
    drawn. The tell is the same every time -- the thing is charged for, so no check
    reports it missing.
    The part is undramatic: G-10 plate 109.04 x 59.41 x 1.6, two end brackets, two
    M4 rods, 12 standoffs, 101.6 g against the 150 g budgeted. Built in Fusion as
    NavBay at Z -127.04 -> -12.00 with the bay's own tube, the nose shoulder and
    the nose plate drawn around it. Drawing it found three things.
    0.80 OF THE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
    [avionics.py, configure.py, sled.py]
2026-09-03 Place the static ports, and find the nav bay has no bare wall
    Three 3.2 mm holes were the last open CAD item in this bay. docs/08 said
    they needed a decision rather than a script; they needed a script, because
    the first question a hole asks is what is behind the wall.
    Two 1.0 cal joints do not fit in a 1.60 cal tube. joints.py described a
    joint only by the half that PROTRUDES, so nothing could ask whether a bay
    had room for the anchored half. `anchor` is a field now, check_joints() is
    the check, the nav bay is exactly full, and the canard module fails by
    15.88 mm and is left open. bay_budget was also taking the max of a bay's
    two narrowed spans instead of their sum: the recovery bay's packi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
    [joints.py, ports.py, sled.py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]
2026-09-03 Resolve the canard module's over-subscribed joint, correction 42's second half
    The nav bay's own joint fix left the canard module failing check_joints() by
    15.88 mm: two 1.0 cal joints charged against its 142.92 mm tube. The real
    constraint is sharper than a convention violation -- the printed hinge/bearing
    bay sits in the MIDDLE of the tube (Z 53.129-94.629 mm), so a coupler bonded
    into either end cannot pass through it.
    design/bay.py gains printed_bay_from_evaluation() and joint_room(), giving the
    real room each joint has before it reaches the printed bay: 50.729 mm forward
    (engagement into the canard module) and 48.291 mm aft (anchor into it), against
    79.40 mm charged each. Sum is 99.02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
    [bay.py, joints.py, ports.py]
2026-09-03 Articulate the hinge in Fusion, and draw the nose cone for the first time
    The canard hinges had working mates in Onshape (correction 39) but nothing
    equivalent existed in Fusion, where the imported STEP components just sat
    unconnected. Four as-built joints per canard (rigid panel-to-shaft, revolute
    shaft-to-tube, axis read off the shaft's own cylindrical face) fix that.
    As-built rather than a regular joint on purpose: it freezes the current
    position instead of snapping geometry to align, which matters when nothing
    but the STEP import's own accuracy holds the parts together. Driven to 8
    degrees and screenshotted before being trusted, then reset to zero -- same
    rule as the Onshape mates.
    Aske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
    [mass.py, nose_module.py]
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
